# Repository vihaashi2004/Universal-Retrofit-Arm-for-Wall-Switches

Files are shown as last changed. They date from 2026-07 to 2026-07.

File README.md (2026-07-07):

# 🔌 Retrofit Switch Controller

**A little robot arm that flips your wall switches for you.**

No rewiring. No replacing your switches with "smart" ones. Just a small device that sits over your existing switch plate, learns where each switch is, and presses it on command — from your phone, or on a schedule you set.

Think of it as teaching a robot finger to do what your finger does, except it never forgets to turn the lights off.

<p align="center">
  <em>🖐️ Teach it your switches → 📱 Control from a web app → ⏰ Automate the rest</em>
</p>

### Why this exists
Smart switches mean rewiring your walls. Smart bulbs mean replacing every bulb. This project skips all of that — it retrofits automation onto switches you already have, with a tiny arm and a web page hosted right on the device itself.

### What it can do
- 👆 **Learns your switches** — just jog the arm to each switch by hand once, hit save, done
- 📱 **Control from any browser** — no app install, connects straight to its own WiFi
- ⏰ **Set it and forget it** — schedule switches daily, on specific days, or for a one-off time
- 🏠 **Works standalone** — has its own WiFi hotspot, and can also join your home network

---

## 🚀 Getting Started

### What you'll need
- [PlatformIO](https://platformio.org/) (VS Code extension or CLI)
- An ESP32 dev board
- A USB cable

### Flash it
```bash
git clone <your-repo-url>
cd retrofit-switch

pio run              # build the firmware
pio run -t upload    # flash it to the board
pio run -t uploadfs  # upload the web UI files
```

### First boot
1. The device starts its own WiFi hotspot: **`Retrofit Switch`** (password: `12345678`)
2. Connect to it and open `192.168.4.1` in a browser (or `retroswitch.local` if it's also joined your home WiFi)
3. Go to the **Switches** tab, jog the arm over to each switch, and save its ON/OFF position
4. If the arm hasn't found its reference position yet, use **Settings → Force Home**

### Using the web app
- **Switches** — jog the arm, teach positions, test each switch with one tap
- **Schedules** — set up daily, day-of-week, or one-time automation
- **Settings** — WiFi setup, homing, and diagnostics

---

## 🗺️ Roadmap

- [ ] Resolve TMC2209 UART communication (see Technical Details below)
- [ ] Re-enable StallGuard-based sensorless homing
- [ ] Host the web app fully on-device to avoid mixed-content issues from the earlier externally-hosted frontend
- [ ] Add per-switch calibration drift compensation
- [ ] Support switch plate layouts beyond 5-gang Quincunx

---

## 🧠 Technical Details

### Hardware

| Component | Detail |
|---|---|
| MCU | ESP32 (Arduino framework, PlatformIO) |
| Stepper drivers | 2× TMC2209 (UART-configurable) |
| Motors | 2× NEMA 17, 1.8°/step, 16x microstepping (3200 steps/rev) |
| Actuator | JF-0530B solenoid (intermittent duty only) |
| Mechanism | 5-bar parallel linkage — L1 = L2 = 50mm, L3 = L4 = 75mm, motor separation D = 47.7mm |
| Switch layout | 5-gang Quincunx switch plate |
| PCB | Custom board, designed in Altium |

### Pin Mapping

| Signal | GPIO | Notes |
|---|---|---|
| Motor 1 (U3) DIR | 4 | |
| Motor 1 STEP | 16 | |
| Motor 1 EN | 17 | Active LOW |
| Motor 1 DIAG | 21 | StallGuard, interrupt-driven |
| Motor 1 PDN_UART | 22 | |
| Motor 2 (U5) DIR | 12 | |
| Motor 2 STEP | 27 | |
| Motor 2 EN | 18 | Active LOW |
| Motor 2 DIAG | 34 | Input-only, polled (no interrupt support) |
| Motor 2 PDN_UART | 25 | |
| Solenoid | 13 | MOSFET gate |

### ⚠️ Current Blocker: TMC2209 UART

- **UART to both TMC2209 drivers is non-functional** (`IFCNT` reads 0 / connection tests return `FAILED` on both drivers). This means StallGuard parameters (`SGTHRS`, `TCOOLTHRS`) can't be configured, so sensorless homing can't run.
- Suspected root cause: PCB-level issues — missing UART split resistor and/or PDN_UART soldering defects on U3/U5.
- **Current workaround:** the system runs in **standalone mode** with potentiometer-based current control, plus a **force-home bypass** that lets you manually set a reference position to unblock movement without StallGuard.
- Until UART is restored, homing accuracy depends on the manual force-home reference rather than automatic stall detection.

**Fix checklist (from schematic review):**
- [ ] Add 1kΩ series resistor on ESP32 TX before joining PDN_UART (half-duplex split)
- [ ] Set MS1/MS2 pins to explicit levels (10kΩ to VCC/GND, don't leave floating)
- [ ] Add 100nF ceramic decoupling caps on VM pins alongside existing electrolytics
- [ ] Verify DIAG/INDEX pins aren't floating
- [ ] Re-check PDN_UART solder joints on U3 and U5

---

## 📄 License

_Add your license here (e.g. MIT)._

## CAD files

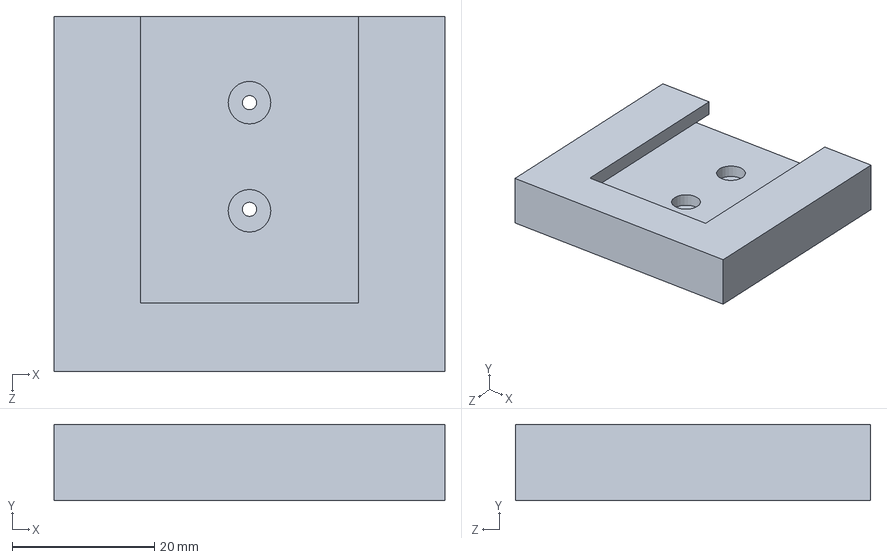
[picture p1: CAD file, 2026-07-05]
Signal_Knights_Solidworks/Signal_Knights_Solidworks/wall bracket.SLDPRT
55.0 x 10.7 x 50.0 mm

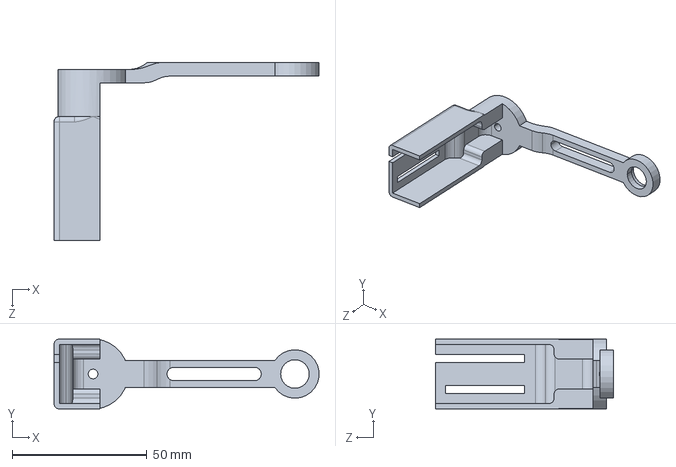
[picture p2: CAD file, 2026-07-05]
Signal_Knights_Solidworks/Signal_Knights_Solidworks/down links 1 for 20N solonoid.SLDPRT
98.4 x 26.0 x 66.0 mm

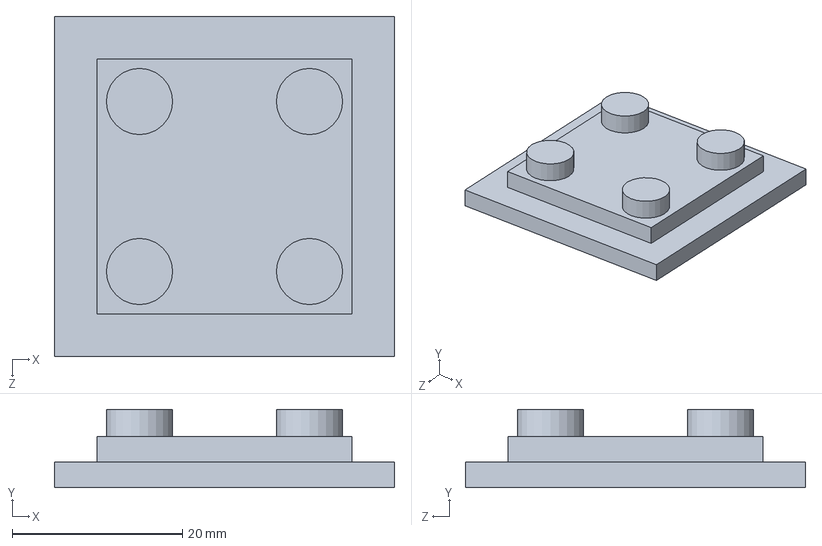
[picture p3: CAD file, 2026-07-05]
Signal_Knights_Solidworks/Signal_Knights_Solidworks/Enclosure Bracket.SLDPRT
40.0 x 9.20 x 40.0 mm

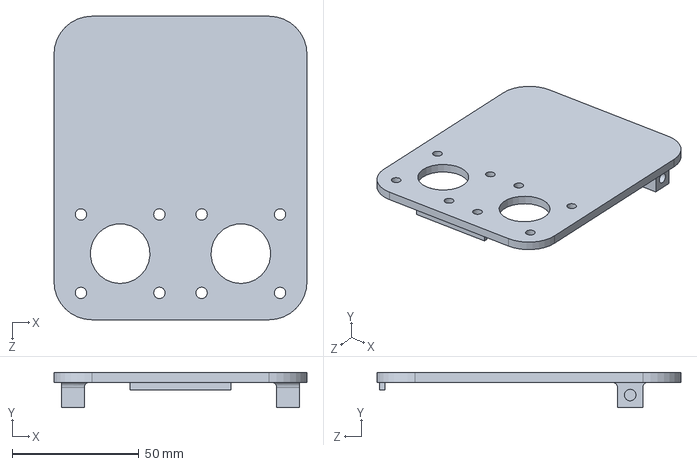
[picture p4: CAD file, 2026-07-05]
Signal_Knights_Solidworks/Signal_Knights_Solidworks/Front PLate.SLDPRT
100.0 x 14.0 x 120.0 mm

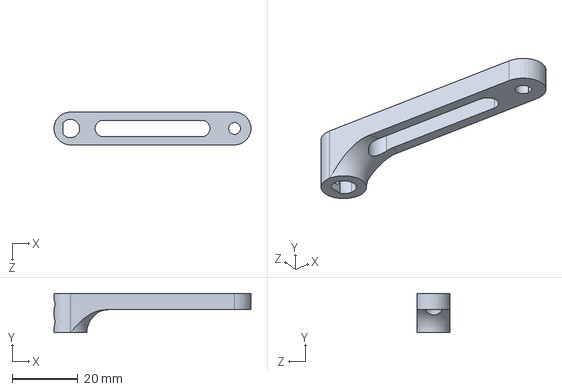
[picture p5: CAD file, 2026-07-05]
Signal_Knights_Solidworks/Signal_Knights_Solidworks/upper links.SLDPRT
60.0 x 12.0 x 10.0 mm

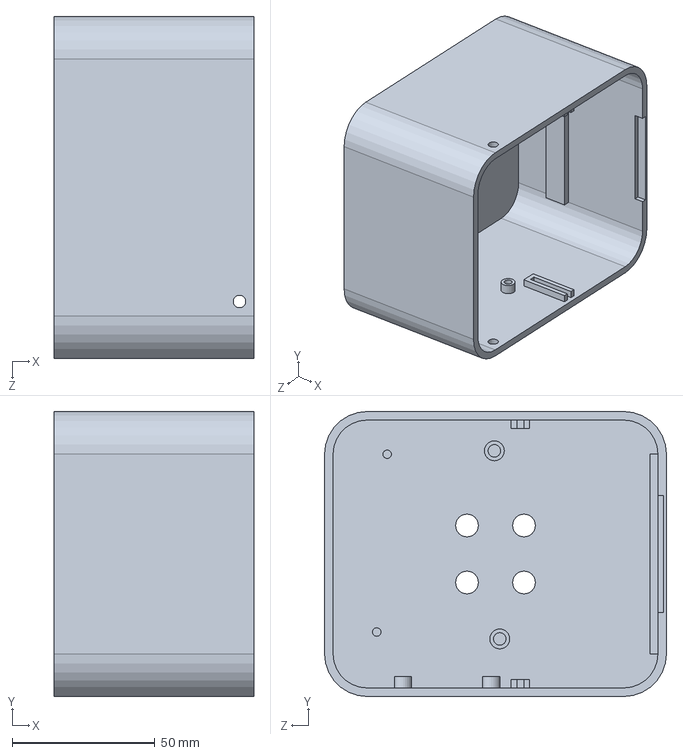
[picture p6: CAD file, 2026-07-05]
Signal_Knights_Solidworks/Signal_Knights_Solidworks/Enclosure shell.SLDPRT
70.0 x 100.0 x 120.0 mm

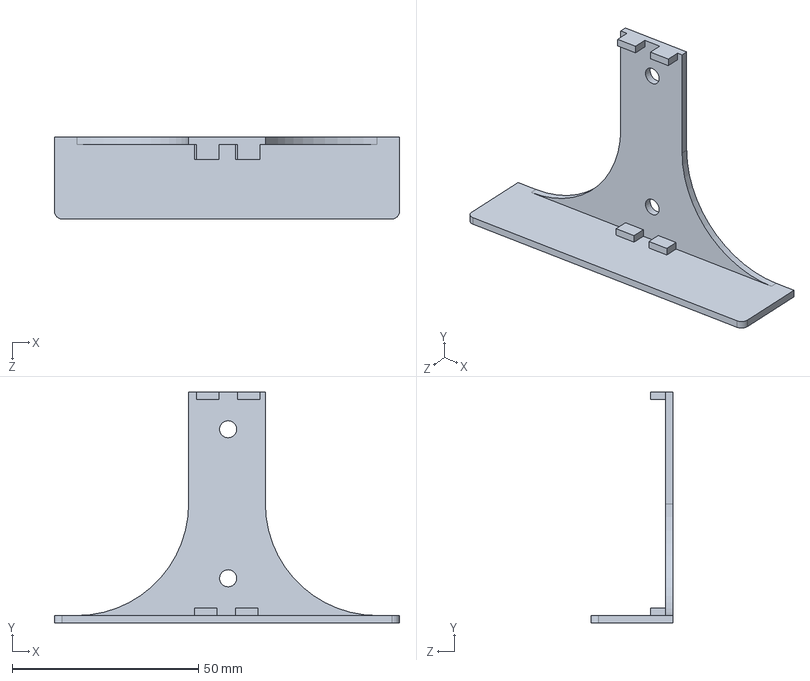
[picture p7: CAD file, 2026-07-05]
Signal_Knights_Solidworks/Signal_Knights_Solidworks/battery shelf.SLDPRT
92.6 x 62.0 x 22.0 mm

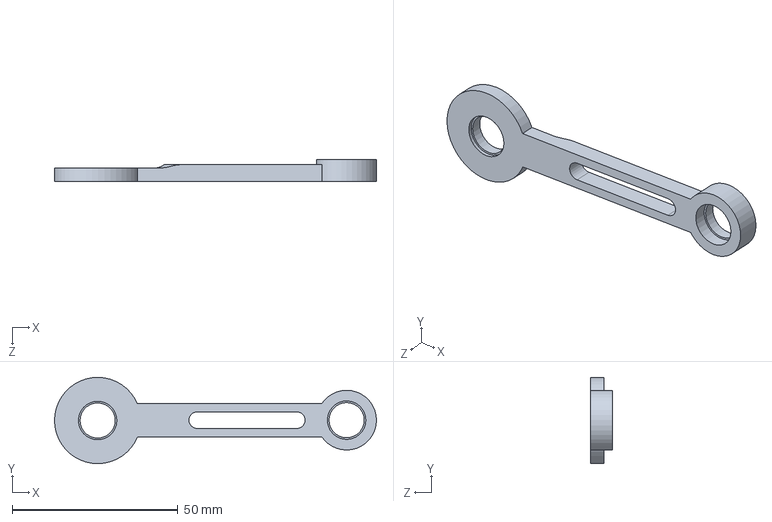
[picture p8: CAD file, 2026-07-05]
Signal_Knights_Solidworks/Signal_Knights_Solidworks/down link 2 for bearings.SLDPRT
97.0 x 26.0 x 6.50 mm

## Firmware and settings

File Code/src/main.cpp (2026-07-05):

#include <Arduino.h>
#include <ArduinoJson.h>
#include <SPIFFS.h>
#include <WebServer.h>
#include <WiFi.h>
#include <time.h>

#include "homing.h"
#include "motor_control.h"
#include "position_control.h"
#include "stepper_driver.h"

// ============================================================
// WiFi Credentials - Router WiFi
// ============================================================
#define WIFI_SSID "Harendra"
#define WIFI_PASSWORD "Harendra1"

// ============================================================
// Web Server
// ============================================================
WebServer server(80);

// ============================================================
// WiFi / AP Settings
// ============================================================
String staSsid = WIFI_SSID;
String staPass = WIFI_PASSWORD;

String apSsid = "RetrofitSwitch";
String apPass = "12345678";

String tzString = "IST-5:30";
String ntpServerString = "pool.ntp.org";

// ============================================================
// Robot State
// ============================================================
float currentX = 0.0;
float currentY = 0.0;

bool motorsRunning = false;
bool apiHomingInProgress = false;
String lastHomeMessage = "Not homed";

// ============================================================
// Switch Config
// ============================================================
const int MAX_SWITCHES = 10;
const int MAX_SCHEDULES = 20;

struct SavedPos {
  bool saved;
  float x;
  float y;
};

struct SwitchConfig {
  String name;
  SavedPos on;
  SavedPos off;
};

SwitchConfig switches[MAX_SWITCHES];
int switchCount = 4;
int switchType = 0;

// ============================================================
// Schedule Config
// ============================================================
struct ScheduleItem {
  int index;
  int switch_index;
  String action;
  String type;
  int hour;
  int minute;
  int days_mask;
  String date;
  bool enabled;
  String last_fire_key;
};

ScheduleItem schedules[MAX_SCHEDULES];
int scheduleCount = 0;
int nextScheduleIndex = 0;

// ============================================================
// JSON Helpers
// ============================================================
template <typename T> void sendJsonDoc(T &doc, int code = 200) {
  String out;
  serializeJson(doc, out);
  server.send(code, "application/json", out);
}

void sendOk(const String &message = "OK") {
  StaticJsonDocument<160> doc;
  doc["success"] = true;
  doc["message"] = message;
  sendJsonDoc(doc);
}

void sendError(const String &message, int code = 400) {
  StaticJsonDocument<256> doc;
  doc["success"] = false;
  doc["message"] = message;
  sendJsonDoc(doc, code);
}

bool parseBody(StaticJsonDocument<1024> &doc) {
  String body = server.arg("plain");

  if (body.length() == 0) {
    sendError("Empty JSON body");
    return false;
  }

  DeserializationError err = deserializeJson(doc, body);

  if (err) {
    sendError("Bad JSON");
    return false;
  }

  return true;
}

String pathSegment(const String &path, int wantedIndex) {
  int start = path.startsWith("/") ? 1 : 0;

  for (int i = 0; i < wantedIndex; i++) {
    int slash = path.indexOf('/', start);
    if (slash < 0)
      return "";
    start = slash + 1;
  }

  int end = path.indexOf('/', start);
  if (end < 0)
    end = path.length();

  return path.substring(start, end);
}

// ============================================================
// SPIFFS Files
// ============================================================
void listSpiffsFiles(const char *dirname = "/") {
  Serial.println("SPIFFS file list:");

  File root = SPIFFS.open(dirname);

  if (!root) {
    Serial.println("Failed to open SPIFFS root");
    return;
  }

  if (!root.isDirectory()) {
    Serial.println("SPIFFS root is not a directory");
    return;
  }

  File file = root.openNextFile();

  while (file) {
    Serial.print("FILE: ");
    Serial.print(file.name());
    Serial.print("  SIZE: ");
    Serial.println(file.size());

    file = root.openNextFile();
  }

  Serial.println("End of SPIFFS file list.");
}

void sendFile(const char *path, const char *type) {
  Serial.print("Trying to open: ");
  Serial.println(path);

  if (!SPIFFS.exists(path)) {
    Serial.print("File not found: ");
    Serial.println(path);
    server.send(404, "text/plain", String("File not found: ") + path);
    return;
  }

  File file = SPIFFS.open(path, "r");

  if (!file) {
    server.send(500, "text/plain", "Failed to open file");
    return;
  }

  server.streamFile(file, type);
  file.close();
}

// ============================================================
// Time
// ============================================================
void applyTimeSettings() {
  setenv("TZ", tzString.c_str(), 1);
  tzset();
  configTime(0, 0, ntpServerString.c_str());
}

bool timeSynced() {
  time_t now;
  time(&now);
  return now > 1700000000;
}

String getNowString() {
  struct tm timeinfo;

  if (!getLocalTime(&timeinfo, 50)) {
    return "";
  }

  char buf[32];
  strftime(buf, sizeof(buf), "%Y-%m-%d %H:%M:%S", &timeinfo);
  return String(buf);
}

// ============================================================
// WiFi
// ============================================================
void startAccessPoint() {
  WiFi.softAP(apSsid.c_str(), apPass.c_str());

  Serial.print("AP SSID: ");
  Serial.println(apSsid);

  Serial.print("AP IP: ");
  Serial.println(WiFi.softAPIP());
}

void connectToRouterWiFi() {
  WiFi.mode(WIFI_AP_STA);
  WiFi.setAutoReconnect(true);
  WiFi.persistent(false);

  startAccessPoint();

  Serial.print("Connecting to router WiFi: ");
  Serial.println(staSsid);

  WiFi.begin(staSsid.c_str(), staPass.c_str());

  unsigned long startAttempt = millis();

  while (WiFi.status() != WL_CONNECTED && millis() - startAttempt < 15000) {
    delay(500);
    Serial.print(".");
  }

  Serial.println();

  if (WiFi.status() == WL_CONNECTED) {
    Serial.println("Router WiFi connected!");
    Serial.print("ESP32 STA IP: ");
    Serial.println(WiFi.localIP());
  } else {
    Serial.println("Router WiFi failed. AP mode still active.");
    Serial.print("Use AP IP: ");
    Serial.println(WiFi.softAPIP());
  }
}

// ============================================================
// Motor / Homing Process
// ============================================================
void runHomingSequence() {
  Serial.println();
  Serial.println("================================");
  Serial.println("REAL HOMING SEQUENCE START");
  Serial.println("Calling homing::home()");
  Serial.println("================================");

  apiHomingInProgress = true;
  lastHomeMessage = "Homing running";

  homing::Result result = homing::home();

  if (result == homing::Result::OK) {
    position_control::setCurrent(0.0f, 0.0f);
    lastHomeMessage = "Homing success";

    Serial.println("================================");
    Serial.println("HOMING SUCCESS");
    Serial.println("================================");
  } else {
    lastHomeMessage = "Homing failed";

    Serial.println("================================");
    Serial.println("HOMING FAILED");
    Serial.println("================================");
  }

  apiHomingInProgress = false;
}

void homeTask(void *parameter) {
  Serial.println("HOME TASK STARTED");

  runHomingSequence();

  Serial.println("HOME TASK FINISHED");
  vTaskDelete(NULL);
}

bool moveToXY(float x, float y) { return position_control::moveToXY(x, y); }

bool jogXY(float dx, float dy) { return position_control::jogXY(dx, dy); }

bool pressSwitch(int idx, String action) {
  if (idx < 0 || idx >= switchCount)
    return false;

  action.toLowerCase();
  bool actuateSolenoid = (idx > 0);

  if (action == "on") {
    if (!switches[idx].on.saved)
      return false;

    if (actuateSolenoid)
      return position_control::pressAtXY(switches[idx].on.x,
                                         switches[idx].on.y);
    else
      return position_control::moveToXY(switches[idx].on.x, switches[idx].on.y);
  }

  if (action == "off") {
    if (!switches[idx].off.saved)
      return false;

    if (actuateSolenoid)
      return position_control::pressAtXY(switches[idx].off.x,
                                         switches[idx].off.y);
    else
      return position_control::moveToXY(switches[idx].off.x,
                                        switches[idx].off.y);
  }

  return false;
}

// ============================================================
// API: Status
// ============================================================
void handleStatus() {
  DynamicJsonDocument doc(1024);

  doc["success"] = true;
  doc["homed"] = homing::isHomed();
  doc["homing_in_progress"] = apiHomingInProgress;
  doc["home_message"] = lastHomeMessage;

  JsonObject wifi = doc.createNestedObject("wifi");
  wifi["sta_connected"] = WiFi.status() == WL_CONNECTED;
  wifi["sta_ip"] =
      WiFi.status() == WL_CONNECTED ? WiFi.localIP().toString() : "";
  wifi["ap_ip"] = WiFi.softAPIP().toString();

  JsonObject timeObj = doc.createNestedObject("time");
  timeObj["synced"] = timeSynced();
  timeObj["now"] = getNowString();

  JsonObject pos = doc.createNestedObject("position");
  pos["x"] = position_control::getX();
  pos["y"] = position_control::getY();

  sendJsonDoc(doc);
}

// ============================================================
// API: Home Button
// ============================================================
void handleHome() {
  Serial.println("================================");
  Serial.println("HOME BUTTON API CALLED");
  Serial.println("POST /api/home received");
  Serial.println("================================");

  if (apiHomingInProgress) {
    sendOk("Homing already running");
    return;
  }

  xTaskCreatePinnedToCore(homeTask, "homeTask", 8192, NULL, 1, NULL, 1);

  sendOk("Homing started");
}

// ============================================================
// API: Force Home (skip obstacle-seeking routine)
// ============================================================
void handleForceHome() {
  if (apiHomingInProgress) {
    sendError("Homing is currently running, wait for it to finish");
    return;
  }

  homing::forceHomeAtCurrentPosition();
  position_control::setCurrent(0.0f, 0.0f);
  resetMotorObstacleStops();

  lastHomeMessage = "Homed manually (obstacle-seek skipped)";

  sendOk("Marked as homed at current position");
}
void handleGetPosition() {
  StaticJsonDocument<384> doc;

  doc["success"] = true;
  doc["x"] = position_control::getX();
  doc["y"] = position_control::getY();
  doc["q1"] = position_control::getQ1();
  doc["q2"] = position_control::getQ2();
  doc["moving"] = position_control::isBusy();
  doc["obstacle_m1"] = motor1ObstacleStopped;
  doc["obstacle_m2"] = motor2ObstacleStopped;

  sendJsonDoc(doc);
}

void handleJog() {
  StaticJsonDocument<1024> body;
  if (!parseBody(body))
    return;

  float dx = body["dx"] | 0.0;
  float dy = body["dy"] | 0.0;

  if (!jogXY(dx, dy)) {
    String err = position_control::lastError();
    sendError(err.length() ? err : "Home first or target invalid");
    return;
  }

  sendOk("Jog started");
}

void handleMoveAbsolute() {
  StaticJsonDocument<1024> body;
  if (!parseBody(body))
    return;

  float x = body["x"] | position_control::getX();
  float y = body["y"] | position_control::getY();

  if (!moveToXY(x, y)) {
    String err = position_control::lastError();
    sendError(err.length() ? err : "Home first or target invalid");
    return;
  }

  StaticJsonDocument<256> doc;
  doc["success"] = true;
  doc["message"] = "Move started";
  doc["x"] = x;
  doc["y"] = y;
  sendJsonDoc(doc);
}

// ============================================================
// API: Obstacle reset — clears the obstacle-stop latch and
// re-enables both drivers so jog/move can power the motors again.
// ============================================================
void handleResetObstacle() {
  resetMotorObstacleStops();
  sendOk("Obstacle flags cleared, motors re-enabled");
}

// ============================================================
// API: Switches
// ============================================================
void handleGetSwitches() {
  DynamicJsonDocument doc(4096);

  doc["success"] = true;
  doc["count"] = switchCount;
  doc["type"] = switchType;

  JsonArray arr = doc.createNestedArray("switches");

  for (int i = 0; i < switchCount; i++) {
    JsonObject sw = arr.createNestedObject();

    sw["index"] = i;
    sw["name"] = switches[i].name;

    JsonObject on = sw.createNestedObject("on");
    on["saved"] = switches[i].on.saved;
    on["x"] = switches[i].on.x;
    on["y"] = switches[i].on.y;

    JsonObject off = sw.createNestedObject("off");
    off["saved"] = switches[i].off.saved;
    off["x"] = switches[i].off.x;
    off["y"] = switches[i].off.y;
  }

  sendJsonDoc(doc);
}

void handleSetSwitchCount() {
  StaticJsonDocument<1024> body;
  if (!parseBody(body))
    return;

  int count = body["count"] | switchCount;
  int type = body["type"] | switchType;

  if (count < 1)
    count = 1;
  if (count > MAX_SWITCHES)
    count = MAX_SWITCHES;

  switchCount = count;
  switchType = type;

  for (int i = 0; i < switchCount; i++) {
    if (switches[i].name.length() == 0) {
      switches[i].name = "Switch " + String(i + 1);
    }
  }

  sendOk("Switch count saved");
}

void handleUpdateSwitchName(int idx) {
  if (idx < 0 || idx >= switchCount) {
    sendError("Invalid switch index", 404);
    return;
  }

  StaticJsonDocument<1024> body;
  if (!parseBody(body))
    return;

  switches[idx].name = String((const char *)(body["name"] | ""));

  if (switches[idx].name.length() == 0) {
    switches[idx].name = "Switch " + String(idx + 1);
  }

  sendOk("Name saved");
}

void handleSaveSwitchPosition(int idx) {
  if (idx < 0 || idx >= switchCount) {
    sendError("Invalid switch index", 404);
    return;
  }

  StaticJsonDocument<1024> body;
  if (!parseBody(body))
    return;

  String state = String((const char *)(body["state"] | ""));
  float x = body["x"] | position_control::getX();
  float y = body["y"] | position_control::getY();

  state.toLowerCase();

  if (state == "on") {
    switches[idx].on.saved = true;
    switches[idx].on.x = x;
    switches[idx].on.y = y;
  } else if (state == "off") {
    switches[idx].off.saved = true;
    switches[idx].off.x = x;
    switches[idx].off.y = y;
  } else {
    sendError("Invalid state");
    return;
  }

  sendOk("Position saved");
}

void handlePress(int idx, String action) {
  bool ok = pressSwitch(idx, action);

  if (!ok) {
    sendError("Switch position not saved or invalid action");
    return;
  }

  sendOk("Press started");
}

// ============================================================
// API: Schedules
// ============================================================
void handleGetSchedules() {
  DynamicJsonDocument doc(4096);

  doc["success"] = true;

  JsonArray arr = doc.createNestedArray("schedules");

  for (int i = 0; i < scheduleCount; i++) {
    JsonObject s = arr.createNestedObject();

    s["index"] = schedules[i].index;
    s["switch_index"] = schedules[i].switch_index;
    s["action"] = schedules[i].action;
    s["type"] = schedules[i].type;
    s["hour"] = schedules[i].hour;
    s["minute"] = schedules[i].minute;
    s["days_mask"] = schedules[i].days_mask;
    s["date"] = schedules[i].date;
    s["enabled"] = schedules[i].enabled;
  }

  sendJsonDoc(doc);
}

void handleAddSchedule() {
  if (scheduleCount >= MAX_SCHEDULES) {
    sendError("Schedule limit reached");
    return;
  }

  StaticJsonDocument<1024> body;
  if (!parseBody(body))
    return;

  ScheduleItem &s = schedules[scheduleCount];

  s.index = nextScheduleIndex++;
  s.switch_index = body["switch_index"] | 0;
  s.action = String((const char *)(body["action"] | "on"));
  s.type = String((const char *)(body["type"] | "daily"));
  s.hour = body["hour"] | 8;
  s.minute = body["minute"] | 0;
  s.days_mask = body["days_mask"] | 0x7F;
  s.date = String((const char *)(body["date"] | ""));
  s.enabled = body["enabled"] | true;
  s.last_fire_key = "";

  scheduleCount++;

  sendOk("Schedule added");
}

int findScheduleByIndex(int idx) {
  for (int i = 0; i < scheduleCount; i++) {
    if (schedules[i].index == idx)
      return i;
  }

  return -1;
}

void handleUpdateSchedule(int idx) {
  int pos = findScheduleByIndex(idx);

  if (pos < 0) {
    sendError("Schedule not found", 404);
    return;
  }

  StaticJsonDocument<1024> body;
  if (!parseBody(body))
    return;

  schedules[pos].switch_index =
      body["switch_index"] | schedules[pos].switch_index;
  schedules[pos].action =
      String((const char *)(body["action"] | schedules[pos].action.c_str()));
  schedules[pos].type =
      String((const char *)(body["type"] | schedules[pos].type.c_str()));
  schedules[pos].hour = body["hour"] | schedules[pos].hour;
  schedules[pos].minute = body["minute"] | schedules[pos].minute;
  schedules[pos].days_mask = body["days_mask"] | schedules[pos].days_mask;
  schedules[pos].date =
      String((const char *)(body["date"] | schedules[pos].date.c_str()));
  schedules[pos].enabled = body["enabled"] | schedules[pos].enabled;

  sendOk("Schedule updated");
}

void handleDeleteSchedule(int idx) {
  int pos = findScheduleByIndex(idx);

  if (pos < 0) {
    sendError("Schedule not found", 404);
    return;
  }

  for (int i = pos; i < scheduleCount - 1; i++) {
    schedules[i] = schedules[i + 1];
  }

  scheduleCount--;

  sendOk("Schedule deleted");
}

void checkSchedules() {
  static unsigned long lastCheck = 0;

  if (millis() - lastCheck < 10000)
    return;
  lastCheck = millis();

  if (!timeSynced())
    return;

  struct tm timeinfo;
  if (!getLocalTime(&timeinfo, 50))
    return;

  int hour = timeinfo.tm_hour;
  int minute = timeinfo.tm_min;
  int wday = timeinfo.tm_wday;

  char dateBuf[12];
  strftime(dateBuf, sizeof(dateBuf), "%Y-%m-%d", &timeinfo);
  String today = String(dateBuf);

  String fireKey = today + " " + String(hour) + ":" + String(minute);

  for (int i = 0; i < scheduleCount; i++) {
    ScheduleItem &s = schedules[i];

    if (!s.enabled)
      continue;
    if (s.hour != hour || s.minute != minute)
      continue;
    if (s.last_fire_key == fireKey)
      continue;

    bool shouldFire = false;

    if (s.type == "daily") {
      shouldFire = true;
    } else if (s.type == "days_of_week") {
      shouldFire = (s.days_mask & (1 << wday));
    } else if (s.type == "one_time") {
      shouldFire = (s.date == today);
    }

    if (shouldFire) {
      pressSwitch(s.switch_index, s.action);
      s.last_fire_key = fireKey;

      if (s.type == "one_time") {
        s.enabled = false;
      }
    }
  }
}

// ============================================================
// API: WiFi
// ============================================================
void handleGetWifi() {
  DynamicJsonDocument doc(1024);

  doc["success"] = true;
  doc["sta_ssid"] = staSsid;
  doc["ap_ssid"] = apSsid;
  doc["sta_connected"] = WiFi.status() == WL_CONNECTED;
  doc["sta_ip"] =
      WiFi.status() == WL_CONNECTED ? WiFi.localIP().toString() : "";
  doc["ap_ip"] = WiFi.softAPIP().toString();

  sendJsonDoc(doc);
}

void handleSetStaWifi() {
  StaticJsonDocument<1024> body;
  if (!parseBody(body))
    return;

  staSsid = String((const char *)(body["ssid"] | staSsid.c_str()));
  staPass = String((const char *)(body["pass"] | staPass.c_str()));

  WiFi.disconnect();
  delay(300);
  WiFi.begin(staSsid.c_str(), staPass.c_str());

  sendOk("Connecting to router WiFi");
}

void handleSetApWifi() {
  StaticJsonDocument<1024> body;
  if (!parseBody(body))
    return;

  apSsid = String((const char *)(body["ssid"] | apSsid.c_str()));
  apPass = String((const char *)(body["pass"] | apPass.c_str()));

  if (apPass.length() < 8) {
    sendError("AP password must be at least 8 characters");
    return;
  }

  WiFi.softAPdisconnect(true);
  delay(300);
  WiFi.softAP(apSsid.c_str(), apPass.c_str());

  sendOk("Access point updated");
}

// ============================================================
// API: Time
// ============================================================
void handleGetTime() {
  DynamicJsonDocument doc(1024);

  doc["success"] = true;
  doc["ntp_server"] = ntpServerString;
  doc["tz"] = tzString;
  doc["now"] = getNowString();
  doc["synced"] = timeSynced();

  sendJsonDoc(doc);
}

void handleSetTime() {
  StaticJsonDocument<1024> body;
  if (!parseBody(body))
    return;

  tzString = String((const char *)(body["tz"] | tzString.c_str()));
  ntpServerString =
      String((const char *)(body["ntp_server"] | ntpServerString.c_str()));

  applyTimeSettings();

  sendOk("Time settings saved");
}
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
void loop() {
  server.handleClient();
  checkSchedules();

  runMotors();
  position_control::update();
}

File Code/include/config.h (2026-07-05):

#pragma once
#include <Arduino.h>

// ---------------- WiFi Credentials ----------------
#define WIFI_SSID "Harendra"
#define WIFI_PASSWORD "Harendra1"

// ---------------- Motor Motion Config ----------------
namespace motorcfg {

constexpr uint16_t RMS_CURRENT_MA = 900;
constexpr uint8_t HOMING_CURRENT_PCT = 70;

constexpr float HOMING_RPM = 8.0f;
constexpr float HOMING_BACKOFF_DEG = 5.0f;

constexpr uint32_t HOMING_TIMEOUT_MS = 15000;
constexpr uint32_t MOVE_TIMEOUT_MS = 8000;

// Normal motor running values
constexpr float MOTOR_MAX_SPEED = 1000.0f;
constexpr float MOTOR_ACCELERATION = 500.0f;
constexpr long MOTOR_TRAVEL_STEPS = 2000;

} // namespace motorcfg

// ---------------- Home Angle Config ----------------
namespace homecfg {

constexpr float HOME_Q1_DEG = 0.0f;
constexpr float HOME_Q2_DEG = 0.0f;

} // namespace homecfg
// ---------------- Five-bar linkage dimensions ----------------
// IMPORTANT: change these to your real measured values in millimetres.
// UI switch positions are X/Y points in this coordinate system.
namespace linkage {
constexpr float L1 = 80.0f;   // Motor 1 proximal arm length, mm
constexpr float L2 = 80.0f;   // Motor 2 proximal arm length, mm
constexpr float L3 = 120.0f;  // Motor 1 distal arm length, mm
constexpr float L4 = 120.0f;  // Motor 2 distal arm length, mm
constexpr float L5 = 100.0f;  // Distance between motor shafts, mm
}

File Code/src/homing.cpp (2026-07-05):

#include "homing.h"
#include "pins.h"
#include "stepper_driver.h"

namespace homing {

static bool s_homed = false;

// =====================================================
// HOMING TEST SETTINGS
// =====================================================

// Speed eka adu/wadi karanna meka wenas karanna
static constexpr float HOMING_RPM = 2.0f;

// Obstacle detect nowunoth motor ekak maximum karakenna puluwan angle eka
static constexpr float MAX_ROTATE_DEG = 50.0f;

// Safety timeout
static constexpr uint32_t HOMING_TIMEOUT_MS = 20000;

// Logical home angle
static constexpr float HOME_Q1_DEG = 0.0f;
static constexpr float HOME_Q2_DEG = 0.0f;

// =====================================================
// Init
// =====================================================
void init() {
  s_homed = false;

  pinMode(pins::M1_DIAG, INPUT);
  pinMode(pins::M2_DIAG, INPUT);

  pinMode(pins::M1_EN, OUTPUT);
  pinMode(pins::M2_EN, OUTPUT);

  // Start disabled
  digitalWrite(pins::M1_EN, HIGH);
  digitalWrite(pins::M2_EN, HIGH);

  Serial.println("[homing] init complete");
}

// =====================================================
// Homed state
// =====================================================
bool isHomed() { return s_homed; }

// =====================================================
// DIAG debounce
// Obstacle confirm wenna consecutive HIGH 3k balanna
// =====================================================
static bool diagConfirmedHigh(uint8_t pin) {
  uint8_t highCount = 0;

  for (uint8_t i = 0; i < 3; i++) {
    if (digitalRead(pin) == HIGH) {
      highCount++;
    }

    delay(3);
  }

  return highCount == 3;
}

// =====================================================
// Check max angle
// =====================================================
static bool reachedMaxRotation(uint8_t motor) {
  float angle = stepper_driver::getCurrentAngle(motor);

  if (angle < 0) {
    angle = -angle;
  }

  return angle >= MAX_ROTATE_DEG;
}

// =====================================================
// HARD stop one motor only
// Stops software jogging AND disables that motor's driver EN pin.
// =====================================================
static void hardStopMotor(uint8_t motor) {
  stepper_driver::stopContinuous(motor);

  if (motor == MOTOR_1) {
    digitalWrite(pins::M1_EN, HIGH); // TMC2209 disable, active LOW
    Serial.println("[homing] Motor 1 HARD STOPPED");
  } else if (motor == MOTOR_2) {
    digitalWrite(pins::M2_EN, HIGH); // TMC2209 disable, active LOW
    Serial.println("[homing] Motor 2 HARD STOPPED");
  }
}

// =====================================================
// Full homing process
// =====================================================
Result home() {
  Serial.println();
  Serial.println("[homing] ===============================");
  Serial.println("[homing] obstacle detect homing started");
  Serial.println("[homing] ===============================");

  s_homed = false;

  bool m1Done = false;
  bool m2Done = false;

  bool m1ObstacleDetected = false;
  bool m2ObstacleDetected = false;

  bool m1LimitReached = false;
  bool m2LimitReached = false;

  bool m1Timeout = false;
  bool m2Timeout = false;

  // IMPORTANT:
  // Use stepper_driver::enable(), not only digitalWrite EN LOW.
  // This enables internal step generation too.
  stepper_driver::enable();

  delay(300);

  // Reset logical angles before test
  stepper_driver::setCurrentAngle(MOTOR_1, 0.0f);
  stepper_driver::setCurrentAngle(MOTOR_2, 0.0f);

  delay(100);

  Serial.println("[homing] both motors starting clockwise");

  stepper_driver::jogContinuous(MOTOR_1, true, HOMING_RPM);
  stepper_driver::jogContinuous(MOTOR_2, true, HOMING_RPM);

  uint32_t startTime = millis();

  while (!m1Done || !m2Done) {

    // =================================================
    // Motor 1 obstacle check
    // =================================================
    if (!m1Done) {
      if (digitalRead(pins::M1_DIAG) == HIGH) {
        if (diagConfirmedHigh(pins::M1_DIAG)) {
          m1ObstacleDetected = true;
          m1Done = true;

          Serial.println("[homing] Motor 1 obstacle detected");
          hardStopMotor(MOTOR_1);
        }
      }

      if (!m1Done && reachedMaxRotation(MOTOR_1)) {
        m1LimitReached = true;
        m1Done = true;

        Serial.println("[homing] Motor 1 reached 180 degree limit");
        hardStopMotor(MOTOR_1);
      }
    }

    // =================================================
    // Motor 2 obstacle check
    // =================================================
    if (!m2Done) {
      if (digitalRead(pins::M2_DIAG) == HIGH) {
        if (diagConfirmedHigh(pins::M2_DIAG)) {
          m2ObstacleDetected = true;
          m2Done = true;

          Serial.println("[homing] Motor 2 obstacle detected");
          hardStopMotor(MOTOR_2);
        }
      }

      if (!m2Done && reachedMaxRotation(MOTOR_2)) {
        m2LimitReached = true;
        m2Done = true;

        Serial.println("[homing] Motor 2 reached 180 degree limit");
        hardStopMotor(MOTOR_2);
      }
    }

    // =================================================
    // Safety timeout
    // =================================================
    if (millis() - startTime > HOMING_TIMEOUT_MS) {
      if (!m1Done) {
        m1Timeout = true;
        m1Done = true;

        Serial.println("[homing] Motor 1 timeout");
        hardStopMotor(MOTOR_1);
      }

      if (!m2Done) {
        m2Timeout = true;
        m2Done = true;

        Serial.println("[homing] Motor 2 timeout");
        hardStopMotor(MOTOR_2);
      }
    }

    delay(2);
  }

  delay(300);

  // Final safety stop
  hardStopMotor(MOTOR_1);
  hardStopMotor(MOTOR_2);

  stepper_driver::disable();

  Serial.print("[homing] Final M1_DIAG = ");
  Serial.println(digitalRead(pins::M1_DIAG));

  Serial.print("[homing] Final M2_DIAG = ");
  Serial.println(digitalRead(pins::M2_DIAG));

  // =====================================================
  // Result check
  // =====================================================
  if (m1Timeout || m1LimitReached || !m1ObstacleDetected) {
    Serial.println("[homing] FAILED: Motor 1 obstacle not detected");
    return Result::TIMEOUT_M1;
  }

  if (m2Timeout || m2LimitReached || !m2ObstacleDetected) {
    Serial.println("[homing] FAILED: Motor 2 obstacle not detected");
    return Result::TIMEOUT_M2;
  }

  // Both obstacles detected successfully
  stepper_driver::setCurrentAngle(MOTOR_1, HOME_Q1_DEG);
  stepper_driver::setCurrentAngle(MOTOR_2, HOME_Q2_DEG);

  s_homed = true;

  Serial.println("[homing] SUCCESS: both motors detected obstacles");
  Serial.println("[homing] homing complete");

  Serial.print("SG1=");
  Serial.print(stepper_driver::getStallGuardResult(MOTOR_1));
  Serial.print(" SG2=");
  Serial.println(stepper_driver::getStallGuardResult(MOTOR_2));

  return Result::OK;
}
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

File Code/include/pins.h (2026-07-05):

#pragma once
#include <Arduino.h>

// =====================================================================
// Pin Definitions — ESP32 Five-Bar Linkage Switch Pressing Controller
// =====================================================================
//
// NOTE (Motor UART Topology): The two TMC2209 drivers are wired to two
// SEPARATE PDN_UART pins (GPIO22 for Motor 1, GPIO25 for Motor 2). This
// firmware therefore uses two independent HardwareSerial ports (UART1 /
// UART2), each half-duplex through a 1k series resistor to one driver.
// If your hardware instead ties both drivers to a single shared UART
// bus, you must re-wire stepper_driver.cpp to use MS1/MS2 address pins
// on one shared HardwareSerial port instead.
//
// NOTE (GPIO34): GPIO34 is input-only and has no internal pull-up/down.
// It is only ever used here as a plain INPUT (StallGuard DIAG read for
// Motor 2). If your TMC2209's DIAG output is open-drain, add an external
// ~10k pull-down resistor on this pin.
// =====================================================================

namespace pins {

// --- Motor 1 ---
constexpr uint8_t M1_DIR   = 4;
constexpr uint8_t M1_STEP  = 16;
constexpr uint8_t M1_EN    = 17;   // Active LOW
constexpr uint8_t M1_DIAG  = 21;   // StallGuard output, interrupt-capable
constexpr uint8_t M1_UART  = 22;   // PDN_UART, half-duplex via 1k resistor

// --- Motor 2 ---
constexpr uint8_t M2_DIR   = 12;
constexpr uint8_t M2_STEP  = 27;
constexpr uint8_t M2_EN    = 18;   // Active LOW
constexpr uint8_t M2_DIAG  = 34;   // Input-only, no pull-up/down, poll only
constexpr uint8_t M2_UART  = 25;   // PDN_UART, half-duplex via 1k resistor

// --- Solenoid ---
constexpr uint8_t SOLENOID = 13;   // MOSFET gate, JF-0530B

// --- TMC2209 UART ---
constexpr uint32_t TMC_BAUD        = 115200;
constexpr uint8_t  TMC_DRIVER_ADDR = 0b00;
constexpr float    TMC_R_SENSE     = 0.11f;

} // namespace pins

// =====================================================================
// Mechanical / motion constants
// =====================================================================
namespace mech {

// 1.8 degree stepper motor = 200 full steps per revolution
constexpr uint16_t STEPS_PER_REV = 200;

// IMPORTANT:
// කලින් මෙතන 16 තිබුණා.
// 180 degrees command කළාම 360 degrees වගේ කැරකුණ නිසා,
// actual driver microstep setting එක 8 වගේ behave වෙනවා.
// ඒ නිසා 8 කරලා තියෙනවා.
constexpr uint16_t MICROSTEPS = 8;

// Steps needed for 1 degree.
// 200 * 8 = 1600 steps per 360 degrees
// 1600 / 360 = 4.444 steps per degree
constexpr float STEPS_PER_DEG =
    (STEPS_PER_REV * MICROSTEPS) / 360.0f;

} // namespace mech

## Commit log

2026-07-05 First Commit to Github
    [EDP_Retrofit.SchDoc, Enclosure Bracket.SLDPRT, Enclosure shell.SLDPRT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]
2026-07-07 Update description of Retrofit Switch Controller
